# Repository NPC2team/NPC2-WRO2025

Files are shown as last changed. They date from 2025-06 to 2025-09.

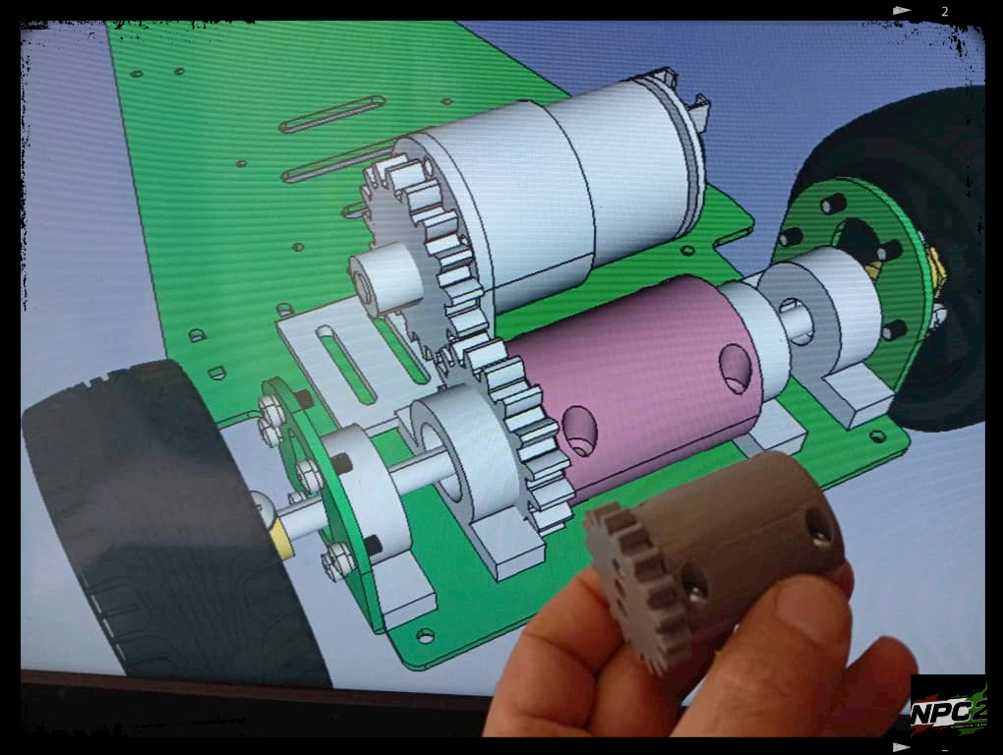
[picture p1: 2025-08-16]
Modifications of the Chassis/017 gear.jpg

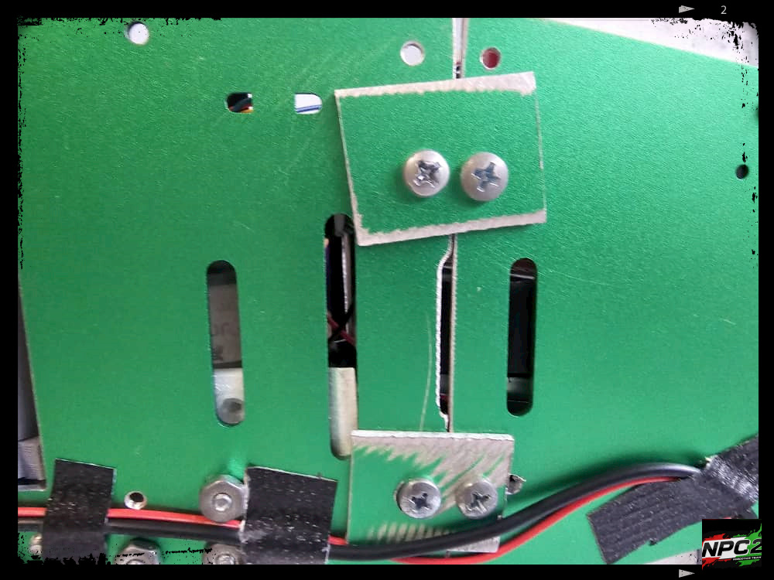
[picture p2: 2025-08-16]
Modifications of the Chassis/011 Joint Chasis2-1.jpg

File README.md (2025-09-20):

NPC2
   

## Table of Contents

- [Our Team](#our-team)
- [Materials](#materials)
- [Car's Construction](#cars-construction)
- [Challenge Problem Solving](#challenge-problem-solving)
- [Electrical Design](#electrical-design)
- [Ackermann Steering Mechanism](#ackeman-steering-mechanism)

## Disclaimer
This repository is the same for the competition of the WRO2025 Venezuela, and the WRO2025 China.
## Our Team

NPC2 is a robotics team from Caracas, Venezuela nationally representing Colegio Jefferson in the World Robotics Olimpiad.  
We have a car named Crazy Diamond and we will be explaning every single detail about him in this repository.
Team Picture:Team FOTO

From left to right: Juan Ignacio González Cardesin, Andrea Jaimes Bselis, Leonardo Carrasquero Recchuiti.
We are competing in the future engineers category of the W.R.O.
The future engineers category consists in 3 mayor challenges:

The first challenge states that the car has to do 3 complete laps in the track and upon finishing stop in the same place it started.

In the second challenge, the car has to do the same three laps while evading obstacles, these oblstacles will vary from color being red or green and depending on the color the car while have to evade them via the right (red) or left (green)  .

During the last challenge the car will start in a parking spot and it has to do the second challenge again, but in this case the car will have to park in the parking spot , this parking must be parelel parking.

## Materials

Watch an explanation of the materials :[Our Materials](https://www.youtube.com/watch?v=jLK10MU_x0E)
[Watch them in accion](https://www.youtube.com/watch?v=ydlA4w6UwqU)
For this competition we had to organize and coordinate with each other in order to narrow down the materials we will use. 
We ended up diciding on the following materials: one motor, one servomotor, one PixyCam2, three ultrasonic sensors, one Arduino R4, one voltage regulator, one H bridge, one 11.1 v battery, and an ackerman steering mecanisim that came with the chasis. 
Below you will see what each material will be used for and why we chose them.

1. The microcontroller that we used is the Arduino R4 WIFI. The Arduino UNO R4 WIFI is an upgraded version of the Arduino UNO, featuring Wi-Fi and Bluetooth connectivity (in this case, due to the competition's rules the Wi-Fi and Bluetooth connectivity is disabled). It’s built around the Renesas RA4M1 microcontroller, which is a 32-bit ARM Cortex-M4 running at 48 MHz, offering significantly more power than the previous 8-bit ATmega328P in the UNO R3. Also this Arduino just needs 5V to start working and in short words, this will be the brain of the car. The Arduino R4 Wi-Fi has 14 digital pins and 6 analogs, so this makes it perfect for us to work. Besides, it's very easy to code in it as it uses a subdivision of C++ called Arduino C++.

Arduino R4:descarga

2. The electronic device we will use to detect colors will be the pixy cam 2 that is a compact, self-contained vision sensor designed to learn objects by their colors. It processes images and quickly outputs data such as the object's signature.
   
Pixy cam: Pixy-2 1-Smart-Vision-Sensor-Object-Tracking-Camera

[Why Pixy?](https://github.com/NPC2team/NPC2-WRO2025/blob/master/Materials/why%20was%20pixy%20chosen.pdf)

3. To help us know where, when, and how to mantain position, we will use ultrasonic sensors that use sonar to measure the distance between themselves and an object. The sensors can measure between 2cm to 400 cm, and they operate at 40 kHz. To complete the challenges, we used 3 ultrasonic sensors. Two of them being in the sides of the car, and one in the front. They are programmed in way so that they will confirm when the car has to cross.

    3D model of ultrasonic sensor: Ultrasonic-Sensor (1)

   The one in the front is a specific model called HRLV, The HRLV‑MaxSonar‑EZ is a high‑resolution, low‑voltage ultrasonic sensor that measures the distance to nearby objects using sound waves.
It offers multiple output formats (analog voltage, pulse width, and serial) for easy integration, and is designed for reliable detection with excellent side‑object rejection.
   It measures distances from 300 mm to 5000 mm (about 12 inches to 16.4 feet) with a 10 Hz read rate, making it perfect for both short‑ and long‑range applications!


5. To power all this we used the Zeee battery Shorty that has 2200 mAh, 3 Lithium polymer. This battery weighs 137 g. It has 11.1V, and its dimmensions are 75mm*34mm*26.5mm.

   Battery: 71m+EHRrMrL

6. To power the motor, and regulate the speed and voltage, we use an H-Bridge, specifically the L298N which is a dual H-bridge motor driver module designed to control the speed and direction of the DC and stepper motors. It operates within a voltage range of 5V to 35V. We connected the H-Bridge to the Arduino using the L298N as an intermediary between the Arduino R4 and the motors.

   L298N: dual-h-bridge-motor-driver-l298n-44325-750x750

7. To regulate the voltage and electricity, we used a voltage regulator that is connected directly to the battery and also powers the DC motor.

   Photo of the voltage regulator:
   modulo-voltaje-ajustable-con-voltimetro-generico-lm2596-step-down-led-digital-2035-2612-1

8. last but not least we have the Servo motor and the DC motor, that are very important because these electronic attachments will help the car move and change dirrections. In the Servo motor's case, it is connected to an Ackerman Steering Wheel that is a physical steering mechanism designed based on Ackermann geometry with the idea that during a turn the inner wheel should turn sharper than the outer wheel so both wheels follow a smooth path. If you are wondering, the Ackerman geometry is a system that ensures a smooth turn by making the inner wheel turn more than the outer one. Meanwhile, the DC motor is part of a mechanism of different gears where it makes the movement of two different wheels possible with just one motor. This mechanism was created using a 3D printer.

   Ackerman steering wheel and Servo photo:
   61U4BQ34BkL _AC_SX522_

   Mechanism of the DC motor:
   

Knowing this, you may wonder what is the chasis that we used, after all it is a very important part of the vehicle because without it, Crazy Diamond wouldn´t exist in the first place.
Well the chasis that we used is a metal chasis that already had the ackerman steering wheel, this chasis can be bought from Amazon. The dimensions of the original chasis are of 337*191*131mm.
[Chasis link](https://www.amazon.com/-/es/inteligente-codificado-estructura-anticolisi%C3%B3n-triangular/dp/B0CWTZC5FQ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) 

Photo of the chasis: 61YIGLu0T0L _AC_SL1500_

## Car's Construccion
Watch an explicatory:[how we created crazy diamond](https://youtu.be/GFbxslP3FUo)

After that we started disarming, destroying, and putting the components that where mencioned before hand.
Adapting the car, evolving it into a wonderful construction, putting the pieces together, and starting to test and view possible ideas for the challenges.

Example of how the proccess should look in Powerpoint: 

The first thing we did to the original chassis was to cut the sides that were near the back wheels and we also cut the chassis in half. We did this so we have less length and avoid the problem of being near the maximum length.

We cut the sides of the chassis so we could add a mechanism that makes it possible for our two back wheels to use only one motor.

Photo of the parts that were about to be cut off:
009 Ajuste Chasis

Photo after the proccess of the car´s adaptation:
018 Enganajes3
019 Enganajes3
017 Enganajes3
011 Joint Chasis2-1

After putting everything where it must go, the car ended up like this:

001 Carro Frontal-1

006 Carro por Debajo

002 Carro Arriba-1

003 Carro Lado Derecho-1

004 Carro Lado Izquierdo-1

005 Carro Trasero-1

## Challenge Problem Solving

[Code explanation](https://www.youtube.com/watch?v=fA16RF1uHUw)

When we finished building the car, we were able to see possible solutions for the challenges.

For the first challenge, we initially planned to do it only with the Pixy camera. The camera signals would be orange and blue, and depending on the color, Crazy Diamond (our car) would spin clockwise or counterclockwise. At the same time, upon detecting the color, a variable will count the number of turns made.
However, we realized it was better to use the ultrasonic sensors for the first challenge, as they allow you to program a code that detects an opening and rotates toward it.
To reinforce the ultrasound idea, we realized it was easier to correct it every time it rotated. This was difficult with the Pixy camera. We also tried to use the VL53L0x or TOF sensor , but we ultimately decided against it because of non consistent measurements when the car was in movement.  We made a document that compared the ultrasonic sensors and the TOF.

[TOFvsULTRASONIC](https://github.com/NPC2team/NPC2-WRO2025/blob/master/Materials/Ultrasonic%20vs%20tof.pdf)

8e7409_c0e539c39a5e4f6d9af293265917e344~mv2

With this we managed to complete the challenge, which can be seen through the link on YouTube.

[First Challenge](https://youtube.com/shorts/cBEeWWgM5bk)

In the second challenge, we combined the Pixy camera with the ultrasonic sensor. The Pixy camera's function would be to detect the red and green blocks. This would allow the car to move toward the blocks and then turn in the direction determined by the block's color.

The ultrasound would have the same function as in Challenge 1: to look for an opening for the car to turn.

Problems in both challenges:

In the first challenge, the main problem was the light illuminating the track, which caused the Pixy camera to misdetect colors or even ignore them, confusing the Arduino.

We managed to solve this problem by using only ultrasound and disabling the Pixy camera for this challenge.

Pixy-2 1-Smart-Vision-Sensor-Object-Tracking-Camera

The second problem was the car's weight, as the battery we were using weighed approximately 500 grams. We solved this by replacing it with a lighter one, that weighs 137 grams.

716CISc+2RL _AC_SX466_

[Why Zeee battery 2200 mAh?](https://github.com/NPC2team/NPC2-WRO2025/blob/master/Energy%20explanation/DETAILED%20POWER%20CONSUMPTION%20ANALYSIS.pdf)

## Electrical Design

[Electric explanation](https://www.youtube.com/watch?v=MQSTbkFTwDA)

The electrical diagrams for the car are shown below.
Final electric diagram with 3 ultrasonic sensors

The circuit starts with a 12V battery that feeds all of the parts. For safety, a main power switch (SW1) turns on or off the whole circuit. The LM2596 step-down regulator is used to convert the 12V supply to a stable 5V output given that some parts need a lower voltage level. These controlled 5 volts are essential so we can power sensitive devices including sensors, the servo motor, and the pixy cam without risking overvoltage damage.

Acting as the main controller of the project is the Arduino UNO R4 WiFi. Directly from the 12V source, the Arduino is driven via its DC connector so ensuring it has enough power even if several accessories are running. Three HC-SR04 ultrasonic sensors are used for distance measurement; one sensor has trigger and echo pins wired to digital pins D2 and D4; another has pins D3 and D5. Moreover, a start button wired to digital pin D10 offers a dependable approach to safely start the action by means of a built-in 10k pull-up resistor.

Concurrent with these sensor links, the circuit drives a motor through an L298N motor driver module. The Arduino controls the enable input and the motor direction inputs (IN3 and IN4) using digital pins D6, D7, and D8. This design is vital for any mobile robotic system because it lets the motor travel in different speeds and directions. This motor controls simplicity and strength making it perfect for applications needing variable movement.

Another important element is the Pixy Cam (CMUcam5), which offers visual processing ability. Through an SPI connection, the Pixy Cam contacts with the Arduino; the MOSI, MISO, and SCK signals are linked to digital pins D11, D12, and D13 respectively, with a dedicated Slave Select (SS) line on pin A0. Real-time picture processing is made possible by this fast communication channel, hence allowing the system to carry out operations such object tracking or visual navigation. Moreover, an SG90 (often) is included to communicate with the mechanical parts, receiving control signals on a PWM pin and working at 5V from the regulator.

The precise pin assignments for sensors, motor drivers, and the camera together with the deliberate distribution of energy from the strong 12V supply to the precisely controlled 5V emphasize the thoughtful integration and equilibrium needed in such an arrangement. Effective mechanical motion control is provided by this design along with sensor data fusing to help with object tracking, obstacle detection, and several user-controllable capabilities.

images

For more details you can check the document: [Diagram Explanation](https://github.com/NPC2team/NPC2-WRO2025/blob/master/Energy%20explanation/DETAILED%20DESCRIPTION%20OF%20ELECTRICAL%20DIAGRAM.pdf)

## ACKEMAN STEERING MECHANISM

An Ackerman steering mechanism is designed to guarantee that a vehicle's front wheels turn at the appropriate angles during a turn, the Ackermann steering mechanism is a cunning mechanical device that enables smooth and effective cornering that helps to avoid tire slippage.
Ackermann steering geometry is a smart configuration of linkages in vehicles designed to guarantee that during a turn the interior and outer front wheels trace separate circular paths. This is because the inner wheel should spin more quickly than the outer wheel to avoid tire scrubbing or slipping, as we said before.


This works because the inner front wheel has to move a closer radius than the outer front wheel as the car turns. In view of the fact, if both wheels were rotated at the same angle, tire wear would occur as the tires scraped against the road, which also reduces control. The Ackermann mechanism solves this issue by arranging the steering angles of each wheel in a way that employs trapezoids to form links. 

We use the Ackerman steering wheel because it reduces tire wear, it improves the handling, and it help the car take directions combined with the servo motor.

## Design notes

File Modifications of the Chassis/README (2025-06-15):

In this file, you will see photos of the changes our team made to the car, The first photo that shows the chassis with some borders colored in black. 
This photo means the parts that we cut off the car that are the sides so we can make a mechanism so the 2 backwheels only use one DC motor.
Then we cut the half of the car that is also colored in black. We cut that so the car length reduces 4 cm aprox.

Then we insert 2 plates underneath the chassis, which are the 2 sides that we cut. We do this so that the 2 halves of the chassis that we cut, come back together.

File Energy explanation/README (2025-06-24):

In this folder you will see every power consumption analysis, each sensors and why we choose them, and the explanation of the final electrical diagram

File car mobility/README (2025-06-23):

In this file you will see different PDF of which materials and components help the  car move and what is the logic behind it

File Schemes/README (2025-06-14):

In this file, you will see two different flow charts corresponding to each of the chalenges and the electrical diagram of the car.

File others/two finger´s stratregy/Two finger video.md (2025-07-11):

[Two finger video](https://youtu.be/SC0VvAZ2L2Q)

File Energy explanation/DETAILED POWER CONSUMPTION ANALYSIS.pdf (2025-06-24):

## DETAILED POWER CONSUMPTION ANALYSIS

### 1. BATTERY SPECIFICATIONS

11.1V 2200mAh LiPo Battery

- Nominal Voltage: 11.1V (3S LiPo)
- Capacity: 2200mAh = 2.2Ah
- Energy Storage: 11.1V × 2.2Ah = 24.42 Wh
- Usable Capacity: ~85% (to prevent deep discharge) = 20.76 Wh
- Voltage Range: 12.6V (full) to 9.6V (empty)

### 2. COMPONENT-BY-COMPONENT POWER ANALYSIS

A. Arduino UNO R4 WiFi (Renesas RA4M1)
Mode | Current Draw Power @ 12V
Idle | 25mA | 0.30W
Processing | 45mA | 0.54W
WiFi Active | 80mA | 0.96W
Typical Running 50mA | 0.60W
B. L298N Motor Driver + DC Motor
Condition | Current Draw Power @ 12V
Driver Quiescent | 35mA | 0.42W
Motor Idle | 50mA | 0.60W
Motor Running (50% PWM) | 400mA | 4.80W
Motor Turning | 600mA | 7.20W
Motor Stalled | 1200mA | 14.40W
Average Navigation | 450mA | 5.40W
C. Servo Motor SG90 (via LM2596)
State | Current @ 5V Power @ 5V Power @ 12V*
Idle | 10mA | 0.05W | 0.06W
Moving | 250mA | 1.25W | 1.47W
Holding Position | 100mA | 0.50W | 0.59W
Average Use | 120mA | 0.60W | 0.71W
D. HC-SR04 Ultrasonic Sensors (×3)
State | Current Each Total (×3) Power @ 5V
Idle | 2mA | 6mA | 0.03W
Measuring 15mA | 45mA | 0.225W
Average | 10mA | 30mA | 0.15W

E. Pixy2 Camera (CMUcam5)
Mode | Current @ 5V Power @ 5V
Idle | 60mA | 0.30W
Tracking 140mA | 0.70W
LED On | 180mA | 0.90W
Typical | 140mA | 0.70W
F. LM2596 Step-Down Regulator
Parameter | Value
Efficiency | 85%
Quiescent Current 5mA
Self Power Loss | 0.06W
Total Overhead | 15% of 5V load
G. System Overhead
Component | Current | Power
Pull-up Resistor | 0.5mA | 0.0025W
Wiring Losses | ~2% | ~0.15W
Total | ~13mA | ~0.15W

### 3. POWER DISTRIBUTION SUMMARY

12V Rail (Direct from Battery)

Component | Current Power
Arduino R4 WiFi | 50mA | 0.60W
L298N + Motor | 450mA | 5.40W
LM2596 Input* | 83mA | 1.00W
Total 12V Rail | 583mA | 7.00W

5V Rail (From Arduino)

Component | Current | Power
3× HC-SR04 | 30mA | 0.15W
Pixy2 Camera | 140mA | 0.70W
Pull-up | 0.5mA | 0.0025W
Total 5V Arduino | 170.5mA | 0.85W

5V Rail (From LM2596)

Component Current Power
Servo SG90 | 120mA | 0.60W

### 4. OPERATING SCENARIOS

Scenario 1: Straight Line Navigation

Arduino: | 50mA × 12V = 0.60W

### Motor (40% PWM): 350mA × 12V = 4.20W

Servo (center): | 50mA × 5V = 0.25W (0.29W @ 12V)
Sensors: | 30mA × 5V = 0.15W
Pixy2: | 140mA × 5V = 0.70W
Overhead: | 0.15W
TOTAL: | ~480mA @ 12V = 6.19W

Scenario 2: Turning Maneuvers

Arduino: | 50mA × 12V = 0.60W

### Motor (60% PWM): 550mA × 12V = 6.60W Servo (turning): 250mA × 5V = 1.25W (1.47W @ 12V)

Sensors: | 45mA × 5V = 0.225W
Pixy2: | 140mA × 5V = 0.70W
Overhead: | 0.20W
TOTAL: | ~750mA @ 12V = 9.58W

Scenario 3: Obstacle Detection & Processing

Arduino (peak): | 70mA × 12V = 0.84W
Motor (stop): | 50mA × 12V = 0.60W

### Servo (active): 150mA × 5V = 0.75W (0.88W @ 12V) Sensors (all): 45mA × 5V = 0.225W Pixy2 (LED on): 180mA × 5V = 0.90W

Overhead: | 0.15W
TOTAL: | ~380mA @ 12V = 4.56W

### 5. BATTERY LIFE CALCULATIONS

Average Power Consumption Profile

Assuming typical maze navigation:

- 60% straight navigation: 6.19W
- 30% turning: 9.58W
- 10% obstacle processing: 4.56W

Weighted Average: (0.6 × 6.19) + (0.3 × 9.58) + (0.1 × 4.56) = 7.05W

Battery Runtime Calculations

Usable Energy: 20.76 Wh (85% of 24.42 Wh)

Average Power: 7.05W

Runtime = 20.76 Wh ÷ 7.05W = 2.94 hours

### 6. PEAK CURRENT ANALYSIS

Maximum Simultaneous Draw:

Arduino (WiFi TX): | 100mA
Motor (stall): | 1200mA
Servo (stall): | 300mA (60mA @ 12V via LM2596)

Sensors (all active): 45mA @ 5V

Pixy2 (LED on): 180mA @ 5V

PEAK CURRENT: ~1400mA @ 12V (15.5W)

Battery C-Rating Check:

- Required: 1400mA ÷ 2200mAh = 0.64C
- Typical LiPo: 20C capable
- Battery can easily handle peak loads

CONCLUSION

11.1V 2200mAh Battery Performance:

- Adequate Capacity: 2.94 hours typical runtime
- Sufficient Current: Can deliver 1.4A peaks easily
- Good Voltage Stability: Maintains >10V for 90% of discharge
- Safety Margin: 20C rating >> 0.64C required

The 11.1V 2200mAh battery is well-suited for this application, providing nearly 3 hours of runtime with comfortable current delivery margins. For competition use, this allows multiple runs with battery to spare.

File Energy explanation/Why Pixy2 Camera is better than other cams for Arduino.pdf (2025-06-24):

## Why Pixy2 Camera is Superior for Arduino-Based Color Obstacle Avoidance

CAMERA OPTIONS COMPARISON

Available Cameras for Arduino:

1. Pixy2 (CMUcam5) - Dedicated color tracking processor
2. OpenMV - Python-programmable vision module
3. ESP32-CAM - WiFi camera with processor
4. OV7670 - Basic camera module
5. ArduCAM - Various models with FIFO buffer
6. HuskyLens - AI vision sensor

### 1. COLOR DETECTION CAPABILITIES

Pixy2 Advantages:

- Hardware-accelerated color detection at 60 FPS
- Can track 7 color signatures simultaneously
- Built-in color-connected components (CCC) algorithm
- No Arduino processing required - outputs object coordinates directly
- Automatic white balance and exposure adjustment

Other Cameras:

OpenMV: 15-30 FPS color detection (Python overhead)

ESP32-CAM: Requires separate processor, 10-15 FPS to Arduino

OV7670: Raw pixels only - Arduino too slow for processing

ArduCAM: 1-5 FPS with Arduino processing

HuskyLens: 20 FPS but limited to preset colors

### 2. REAL-TIME PERFORMANCE COMPARISON

Camera | Color Detection FPS | Latency | Arduino Load
Pixy2 | 60 FPS | <20ms | ~5% (SPI only)
OpenMV | 15-30 FPS | 50-100ms | ~10% (UART)
ESP32-CAM | 10-15 FPS | 100-200ms | ~20% (Serial)
OV7670 | <1 FPS | >1000ms | 100% (unusable)
ArduCAM | 1-5 FPS | 200-500ms | ~80%
HuskyLens | 20 FPS | 50ms | ~10% (I2C)

### 3. COLOR OBSTACLE AVOIDANCE SPECIFIC FEATURES

Pixy2 Unique Advantages:

1. Color Code Detection: Can identify combinations of colors (e.g., red-green-red pattern)
2. Object Size Filtering: Reports width/height for distance estimation
3. Tracking Algorithm: Maintains object ID between frames
4. Pan/Tilt Support: Can actively track moving obstacles

### 4. TECHNICAL SPECIFICATIONS COMPARISON

Feature | Pixy2 | OpenMV | ESP32-
CAM
| | OV7670 | ArduCA M | HuskyLens
Resolution | 316x208 | 320x240 | 1600x120
| 0 | 640x480 | Various | 320x240
Processor | NXP
LPC4330
STM32H743 | ESP32 | None | None | Kendryte K210
Color | Built-in | Programmabl | Requires | Manual | Manual | Pre-trained
Tracking | | e | coding
Interface | SPI/I2C/U
ART

SPI/I2C/UAR
T

WiFi/Seri
al
Parallel | SPI | I2C/UART

### 5. COLOR DETECTION ALGORITHMS

Pixy2 Color Connected Components (CCC):

- HSV color space processing in hardware
- Automatic region growing algorithm
- Real-time connected component labeling
- Outputs: X, Y, Width, Height, Signature ID

Why Others Struggle:

OV7670/ArduCAM:

- Must transfer raw RGB pixels (307KB/frame)
- Arduino processes each pixel (too slow)
- No hardware acceleration

ESP32-CAM:

- Powerful but separate processor
- Complex integration with Arduino
- WiFi overhead if used

OpenMV:

- Excellent but overkill for simple color tracking
- More expensive than Pixy2
- Python interpreter overhead

### 6. OBSTACLE AVOIDANCE PERFORMANCE

Critical Metrics for Navigation:

Response Time to New Obstacle:

- Pixy2: 16ms (1 frame at 60 FPS)
- OpenMV: 33-66ms
- ESP32-CAM: 100-200ms
- OV7670: >1000ms (unusable)

Multiple Obstacle Tracking:

- Pixy2: 7 colors/objects simultaneously
- HuskyLens: 1-2 objects
- Others: Depends on Arduino processing power

### 7. POWER AND RESOURCE EFFICIENCY

Camera | Current Draw Arduino RAM Used Arduino Flash Used
Pixy2 | 140mA | <1KB | ~10KB library
OpenMV | 140mA | 2KB | 15KB library
ESP32-CAM | 160mA | 2KB | 20KB library
OV7670 | 40mA | 8KB+ buffer | 30KB+ code
ArduCAM | 80-120mA | 4KB buffer | 25KB code

CONCLUSION: Why Pixy2 was our choice

For Arduino-based color obstacle avoidance, Pixy2 is the optimal choice because:

1. Dedicated Vision Processor: Offloads ALL vision processing from Arduino
2. Real-time Performance: 60 FPS ensures immediate obstacle detection
3. Proven Reliability: Used in thousands of robotics projects
4. Simple Integration: 5 lines of code vs. hundreds
5. Multiple Object Tracking: Essential for complex environments
6. Power Efficiency: Comparable to alternatives despite superior performance

Bottom Line: While ESP32-CAM is cheaper and OpenMV is more flexible, Pixy2's purpose-built design for color tracking makes it the superior choice for real-time obstacle avoidance. The hardware acceleration and zero Arduino processing overhead are game-changers for responsive navigation.

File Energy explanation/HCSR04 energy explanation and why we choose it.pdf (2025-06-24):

Why we choose HC-SR04 Ultrasonic Sensors and not VL53L0X TOF Sensors?

### 1. TECHNOLOGY DIFFERENCES

HC-SR04 (Ultrasonic)
- Uses sound waves at 40kHz frequency
- Measures time-of-flight of acoustic pulses
- Wavelength: ~8.5mm (much larger than surface irregularities)
- Detection cone: 15-30° typical
VL53L0X (TOF)
- Uses infrared laser at 940nm wavelength
- Measures time-of-flight of light pulses
- Wavelength: ~0.94μm (microscopic)
- Detection cone: 25° typical (but effective spot is smaller)

### 2. PERFORMANCE WITH BLACK SURFACES

HC-SR04 Advantages:
- Acoustic waves are color-blind - sound reflects equally from black, white, or any colored surface
- Surface absorption affects amplitude, not time measurement
- Black surfaces reflect ultrasound just as effectively as white surfaces
- No dependency on optical properties of the target
VL53L0X Disadvantages:
- Black surfaces absorb ~90-95% of IR light
- Dramatically reduced signal-to-noise ratio
- May fail to detect black walls entirely at longer distances
- Requires significantly more power to compensate for absorption
- False readings or "no detection" errors are common

### 3. ANGLED SURFACE BEHAVIOR

HC-SR04 with Angled Surfaces:
- Wide beam pattern (15-30°) captures reflections even from angled surfaces
- Sound waves create multiple reflection paths
- Can detect walls at angles up to 45° reliably
- Diffuse reflection pattern helps maintain detection
VL53L0X with Angled Surfaces:
- Specular reflection - laser beam reflects away from sensor
- Narrow effective beam requires perpendicular surfaces
- Angles >15° often result in no return signal
- Mirror-like reflection on smooth surfaces causes complete signal loss

### 4. NAVIGATION SPECIFIC ADVANTAGES

Wall Following Capability:
HC-SR04: Reliable detection at various angles

- Can detect walls while turning
- Maintains readings during diagonal approaches
- Effective for corner detection

VL53L0X: Loses signal during turns
- Requires perpendicular alignment
- Misses angled walls
- Poor corner detection

Opening Detection:
The HC-SR04's wider beam pattern actually helps in detecting openings:
- Gradual distance increase as approaching an opening
- Natural averaging effect reduces noise
- Clear threshold detection for 70cm+ openings

### 5. TECHNICAL COMPARISON FOR BLACK MAZE WALLS

Parameter | HC-SR04 | VL53L0X
Black Surface Range | 2-400cm | 5-50cm (unreliable)
Angled Surface (30°) | 90% detection | <20% detection
Response Time | 20-30ms | 20-30ms
Power Consumption | 15mA | 20mA average
Reliability in Maze | Excellent | Poor

CONCLUSION
The VL53L0X's advantages (precision, size, speed) are negated by its fundamental inability to reliably detect black surfaces at angles - a critical requirement for maze navigation. The HC-SR04's "inferior" technology actually becomes superior for this specific application where robust detection matters more than precision.

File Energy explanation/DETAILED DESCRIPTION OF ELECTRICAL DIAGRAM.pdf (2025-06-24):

## DETAILED DESCRIPTION OF ELECTRICAL DIAGRAM

### 1. POWER SYSTEM

Main Power Source

- Battery: 12V DC
- Main Switch (SW1): Controls entire system power via ON/OFF switch that interrupts battery positive terminal

Voltage Regulation

- LM2596 Step-Down Module:
- Input: 12V from main bus (after switch)
- Output: Adjustable 5V via potentiometer
- Type: Buck switching converter (high efficiency ~92%)
- Includes operation indicator LED
- Powers servo motor exclusively

Power Distribution

- 12V Bus: Directly powers:
- L298N Motor Driver (VS terminal)
- Arduino R4 WiFi (via DC Jack)
- LM2596 regulator input
- Arduino 5V Bus: Powers:
- 3 HC-SR04 sensors
- Pixy Camera
- Start button pull-up

### 2. MAIN CONTROLLER

Arduino UNO R4 WiFi

- Processor: Renesas RA4M1 (ARM Cortex-M4 @ 48MHz)
- Integrated WiFi connectivity
- Power: 12V via DC Jack (internal regulation to 5V)
- Provides regulated 5V for peripherals

### 3. MOTION SYSTEM

DC Motor

- Controlled by L298N driver

- L298N Connections:
- ENB → Pin D6 (PWM speed control)
- IN3 → Pin D8 (direction)
- IN4 → Pin D7 (direction)
- OUT3/OUT4 → DC motor terminals
- VS → 12V from main bus
- GND → Common ground

Servo Motor SG90

- Vehicle steering control
- Connections:
- PWM → Pin D9 (control signal)
- VCC → 5V from LM2596 regulator (dedicated power)
- GND → Common ground

### 4. SENSOR SYSTEM

Three HC-SR04 Ultrasonic Sensors

### 1. RIGHT Sensor:

- TRIG → Pin D2
- ECHO → Pin D3
- VCC → Arduino 5V
- GND → Common ground

### 2. LEFT Sensor:

- TRIG → Pin D4
- ECHO → Pin D5
- VCC → Arduino 5V
- GND → Common ground

### 3. FRONT Sensor:

- TRIG → Pin A1
- ECHO → Pin A2
- VCC → Arduino 5V
- GND → Common ground

Pixy Camera (CMUcam5)

- SPI interface for computer vision
- SPI Connections:
- MISO → Pin D12

- MOSI → Pin D11
- SCK → Pin D13
- SS → Pin A0
- VCC → Arduino 5V
- GND → Common ground

### 5. CONTROL SYSTEM

START Button

- Connected to Pin D10
- 10kΩ pull-up resistor to 5V
- Pressing connects pin to ground (inverse logic)
- Allows robot program initialization

### 6. DETAILED CONNECTIONS

Digital Pins Used:

- D2: Right sensor TRIG
- D3: Right sensor ECHO
- D4: Left sensor TRIG
- D5: Left sensor ECHO
- D6: Motor ENB (PWM)
- D7: Motor IN4
- D8: Motor IN3
- D9: Servo PWM
- D10: Start button
- D11: MOSI (SPI - Pixy)
- D12: MISO (SPI - Pixy)
- D13: SCK (SPI - Pixy)

Analog Pins Used:

- A0: SS (Pixy Camera)
- A1: Front sensor TRIG
- A2: Front sensor ECHO

### 7. POWER FLOW

1. 12V Battery → ON/OFF Switch → 12V Bus
2. 12V Bus splits to:
- → Arduino DC Jack (internal regulation)
- → L298N VS (motor power)
- → LM2596 IN (to generate 5V)
3. Arduino 5V pin → HC-SR04 Sensors + Pixy + Pull-up

4. LM2596 OUT → Servo motor (dedicated 5V)

### 8. IMPORTANT FEATURES

Common Ground (GND)

- All components share same ground reference
- Ground bus connects: battery, Arduino, L298N, LM2596, sensors, servo, and Pixy

Protections

- Main switch for complete power cutoff
- Separate regulation for servo (prevents voltage drops)
- Pull-up on Start button (prevents erratic readings)

Diagram Color Codes

- Thick black: Main power lines
- Thin black: Digital signals
- Blue: Motor control signals
- Green: Ultrasonic sensor signals
- Orange: Servo PWM signal
- Purple: Pixy SPI bus
- Red: 5V from regulator to servo

### 9. DESIGN ADVANTAGES

1. Robust power supply: Separate regulation prevents interference
2. Modular: Easy to add/remove components
3. Diagnostics: LED on LM2596 indicates operation
4. Flexibility: Integrated WiFi allows remote control
5. Safety: Main switch cuts all power
6. Complete navigation: 3 sensors cover 180° vision

This design enables an autonomous navigation robot capable of detecting obstacles in three directions, with computer vision and precise motion control, all with a robust and well-organized electrical architecture.

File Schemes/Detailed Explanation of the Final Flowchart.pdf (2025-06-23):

Detailed Description of the Autonomous Navigation System
1. Initialization and Boot
The system begins with an initialization phase where all hardware components are configured. The home button pin is first set with internal pull-up resistance, allowing it to detect when the user is ready to start. The program waits indefinitely until the button is pressed, displaying the message "Press the button to start" through the serial port.
Once the button press is detected, the system waits for it to release and then enters a 2-second pause before proceeding. During this time set up:
Motor pins (ENB, IN3, IN4) for speed and steering control.
The servo motor on pin 9, positioning it at its central angle (88°).
The three ultrasonic sensors with their respective trigger and echo pins.
2. Main Operating Cycle
The program enters a continuous loop that executes the following operations every 50 milliseconds:
2.1 Status Check
First, check if the variable CareerFinished is true. If it is, it stops the engine and stays in that state indefinitely.
2.2 Sensor Reading
If the race is not over, proceed to ALWAYS read the three ultrasonic sensors:
Right sensor: Measures the distance to the right wall.
Left sensor: Measures the distance to the left wall.
Front sensor: Measures forward distance.
Each sensor takes 3 consecutive readings and calculates the average for a more reliable measurement. Invalid readings (greater than 400cm or without echo) are discarded. The entire reading process takes approximately 180ms.
3. Navigation Logic
The control logic is divided into two distinct behaviors depending on whether the vehicle has made its first turn or not:
3.1 Before the First Spin (Spin Counter = 0)
In this initial phase, the vehicle has a "confident" and simplified behavior:

Opening detection: Checks if there is an opening (distance > 100cm) to the right or left.

If it detects opening on the right:
Rotates the servo to 133° and keeps the motor moving forward for 1800ms
Set turn direction = 0 to remember to keep turning right
Reduces motor speed from 122 to 120 (post-turn fine adjustment)
If it detects opening on the left:
Rotate the servo to 33° and keep the motor moving forward for 1800ms
Set turn direction = 1 to remember to keep turning left

If it detects no openings: Just go straight WITHOUT applying any correction, keeping the servo at 88°
After any turn, apply an additional delay of 2000ms to avoid multiple detections of the same aperture.
3.2 After the First Spin (Spins counter > 0)
Once the first turn has been made, the behavior changes according to the direction set:
If turn direction = 0 (right):
Just look for openings on the right
If there is no opening, apply the proportional correction system

If turn direction = 1 (left):
Just look for openings on the left-If there is no opening, apply the proportional correction system-
4. Proportional Correction System
This system is only activated after the first turn and when both walls are present (distance < 100cm on both sides):
Behaviour:
If you need minor adjustments:

Calculation: difference = distanceLeft – distanceRight. If it differs > 15cm: It is closer to the right wall.
Applies soft correction to the left (68° servo).
Holds for 325ms.

If it differs < -15cm: It is closer to the left wall Applies gentle correction to the right (servo at 105°). Holds for 325ms.

If -15cm ≤ difference ≤ 15cm: It is sufficiently centered Continue straight without correction.

5. Turn Control and Completion
5.1 Spin Counter
Each time the vehicle detects and takes an opening: Increments CounterSpin
Shows by serial the turn number and direction After each turn, wait 2000ms before continuing

5.2 Completion of the Race
When the Spins counter reaches 12 (equivalent to 3 full spins): Displays "Last Spin Completed!"
Center the servo and move straight forward for an additional 2000ms Completely stops the engine
Set CareerFinished = true
The program remains in a stopped state
6. Security Features
Average Readings: Reduces measurement errors

Continuous check during corrections: You can cancel a correction if you detect an opening Post-turn delays: Avoid detecting the same opening multiple times.
Front Sensor: Adds an extra layer of safety against frontal collisions.
Timeouts on sensors: Prevents the program from freezing if a sensor fails.
7. Debug Information
The system sends continuously by serial port (115200 baud):
The three distances measured in each cycle
Opening detection
Type of correction applied (AGGRESSIVE/SOFT)
Number of turns made
Special states (start, end)

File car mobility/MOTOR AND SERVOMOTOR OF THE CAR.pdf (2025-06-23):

## MOTOR AND SERVOMOTOR OF THE

## CAR

In this PDF, you will see what motor we use, what servomotor we use, how we select them, and how we put it in the car.

## MOTOR

For the car we use a DC motor with an encoder, a DC motor with encoder combines a simple brushed motor where DC voltage spins the armature with an optical or magnetic sensor that generates pulse (quadrature) signals! A controller uses these signals to track speed and position for precise, closed loop control!

The model of the DC motor with an encoder that we use is MD520Z19_12V. That is this one:

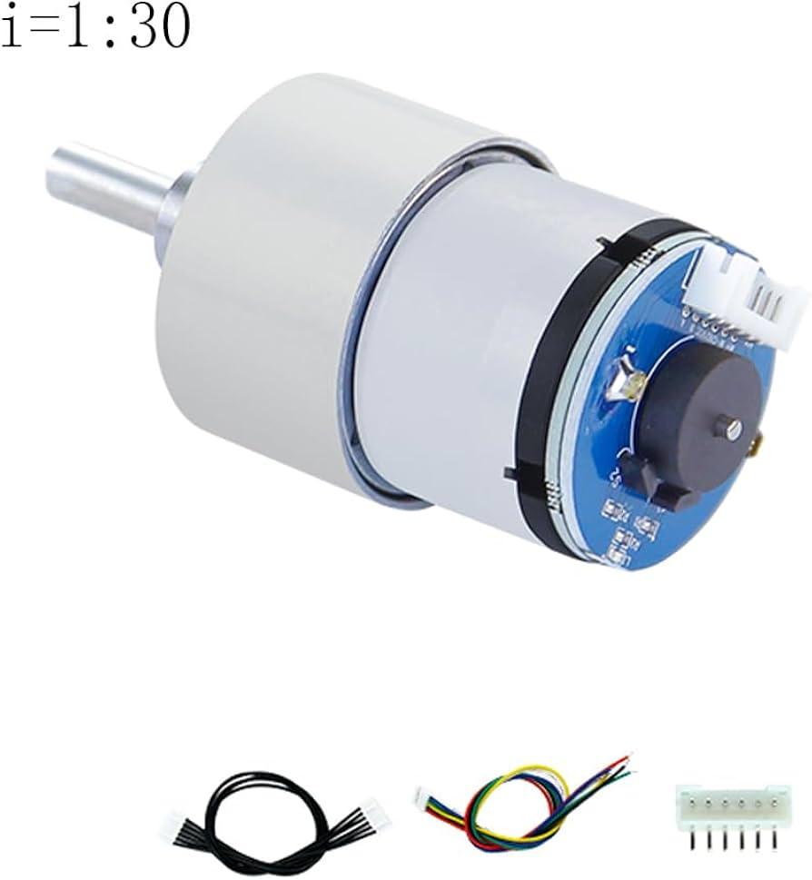
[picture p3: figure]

The main reasons we use this motor are:

- The rated voltage is of 12V which is perfect for our battery and car.
- The motor can reach 11000 rpm before deacceleration.
- It has an encoder which can help us.
- And the last reason is that compare to other DC motors, this one has more power.

## SERVOMOTOR

A servomotor is a type of electric motor designed for precise control of angular or linear position, speed, and torque.

We use a 20 Kg Cm servomotor, and the model is YB-P20M where the voltage is of 7.6V. The main reason we use this servomotor is because it helps us to change the direction of the car and it complements the Ackerman steering mechanism.

The servo motor is the one below:

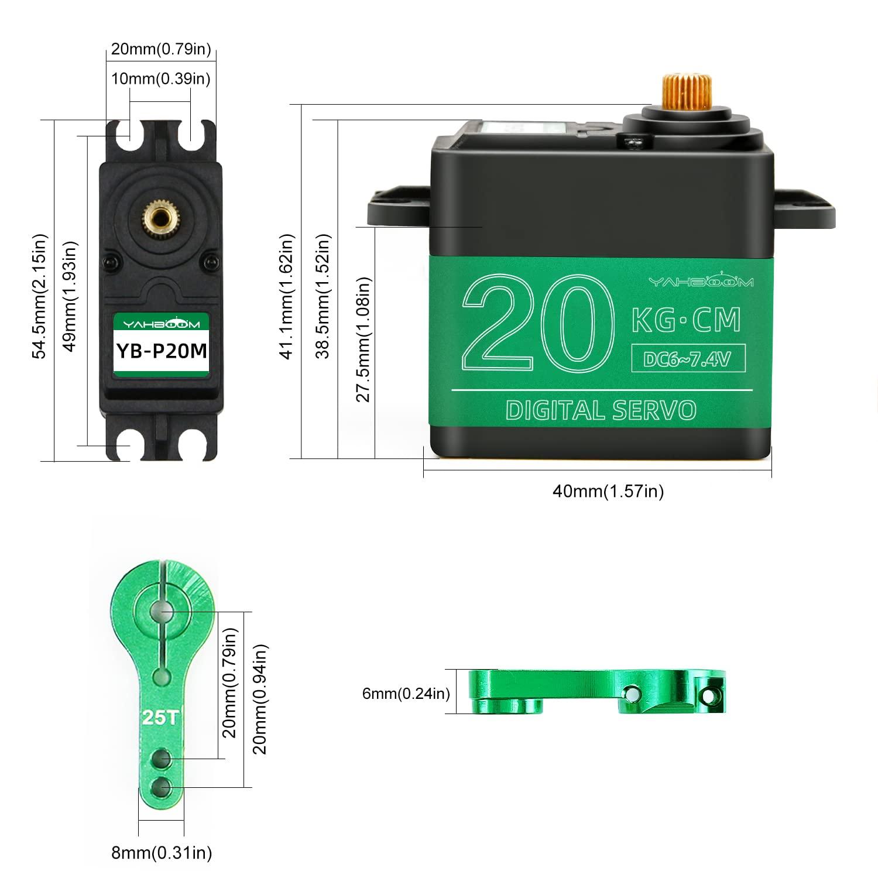
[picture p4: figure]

## HOW WE PUT IT ON THE CAR

First of all, the servo motor is installed in the front of the chassis, and it is fixed by some screws.

The motor is in the back of the chassis and we put a mechanism that is this one

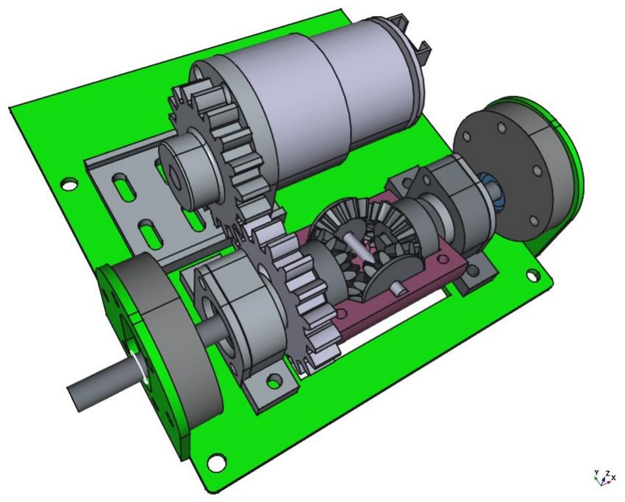
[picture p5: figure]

All this mechanism are created using 3D printer.

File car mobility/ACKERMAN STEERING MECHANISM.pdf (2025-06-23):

## ACKERMAN STEERING MECHANISM

Designed to guarantee that a vehicle's front wheels turn at the appropriate angles during a turn, the Ackermann steering mechanism is a cunning mechanical device that enables smooth and effective cornering that helps to avoid tire slippage.

## ACKERMAN STEERING GEOMETRY

Ackermann steering geometry is a smart configuration of linkages in vehicles designed to guarantee that during a turn the interior and outer front wheels trace separate circular paths. This is because the inner wheel should spin more quickly than the outer wheel to avoid tire scrubbing or slipping, as we said before.

This works because the inner front wheel has to move a closer radius than the outer front wheel as a car turns. In view of the fact if both wheels were rotated at the same angle, wear would occur as the tires scraped against the road, which also reduces control. The Ackermann mechanism solve this issue by arranging the steering angles of each wheel in a way that employs trapezoids to form links.

An example of this is the picture below:

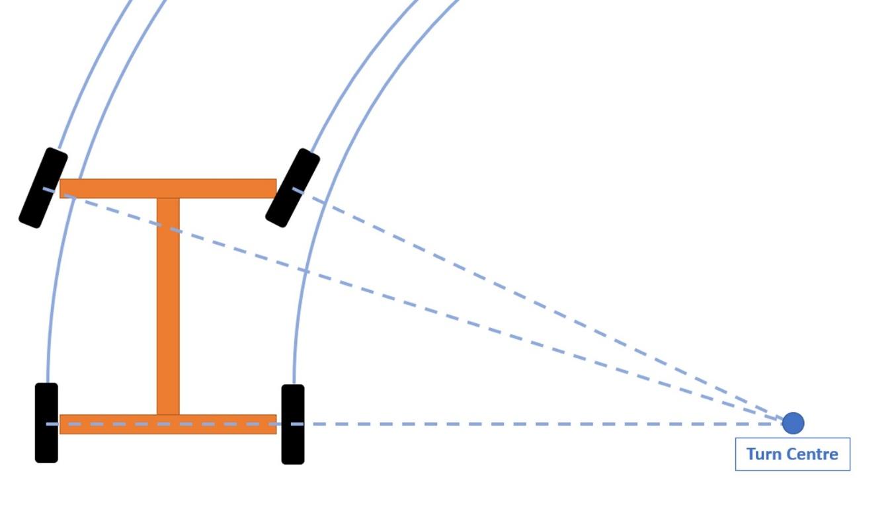
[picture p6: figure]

## KEY COMPONENTS

Steering arms attached to each front wheel.

- A tie rod connecting the arms.
- A steering linkage that moves the tie rod when the steering wheel is turned.

## WHY WE USE IT?

We use the Ackerman steering wheel because it reduces tire wear, it improves the handling, and it help the car take directions combined with the servo motor.

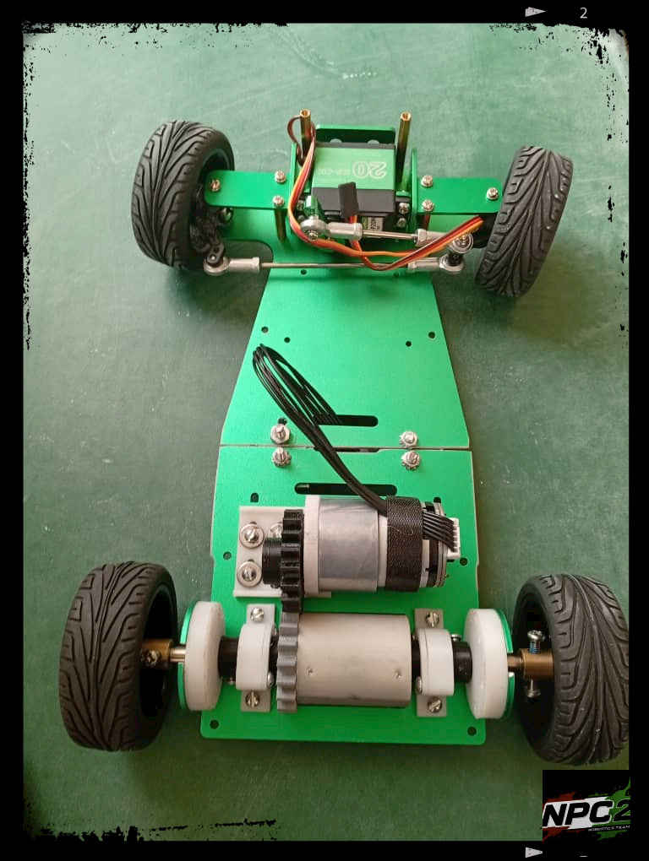
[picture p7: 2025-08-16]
Modifications of the Chassis/019 gear3.jpg

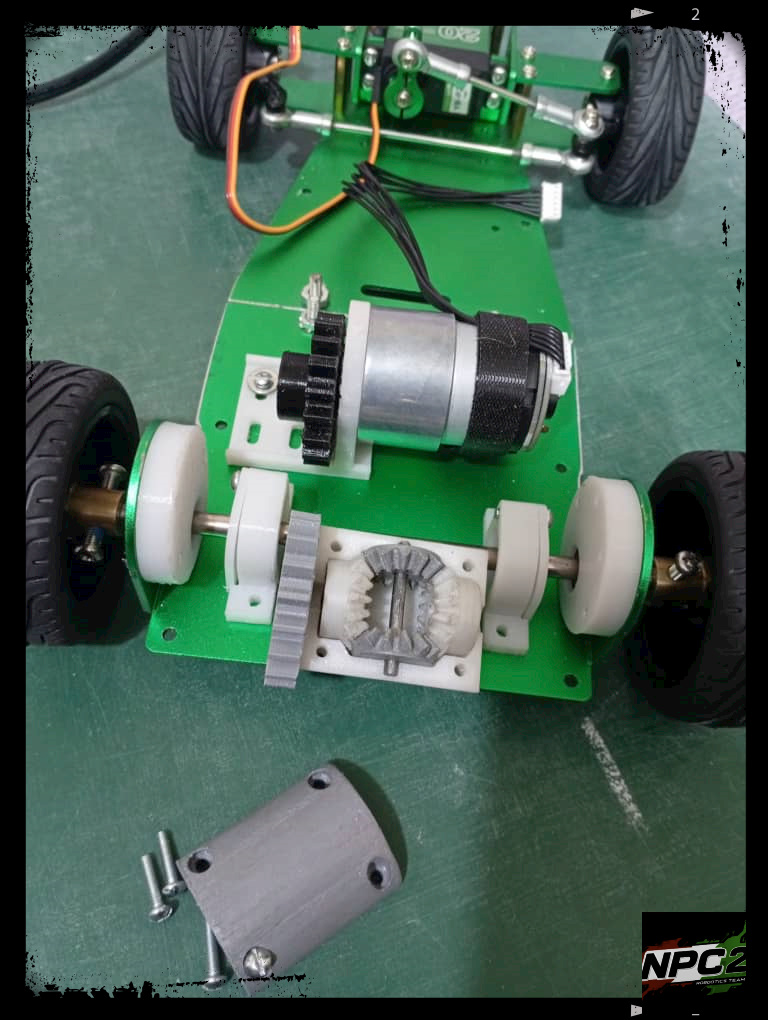
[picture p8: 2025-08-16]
Modifications of the Chassis/018 gears2.jpg

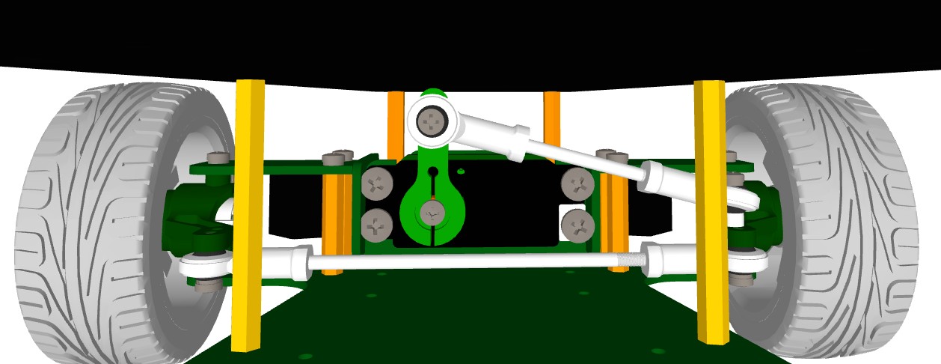
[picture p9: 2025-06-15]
Models/Ackerman y Servo.jpg

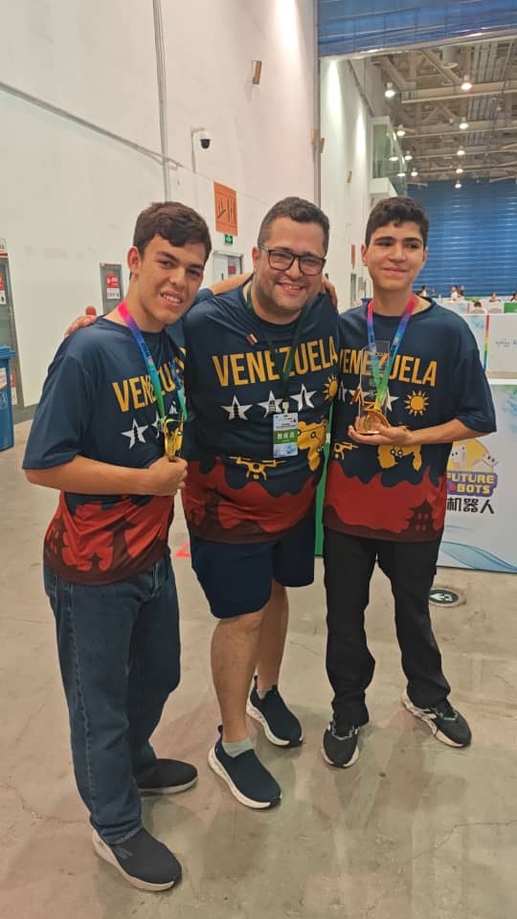
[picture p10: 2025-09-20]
others/photos of the competition from China/Photo with our coach.JPG

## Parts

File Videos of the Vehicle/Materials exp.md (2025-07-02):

[Our Materials](https://www.youtube.com/watch?v=jLK10MU_x0E)

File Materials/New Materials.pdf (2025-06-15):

# NEW MATERIALS

In these presentation, you will see the materials that we are going to use for the car.

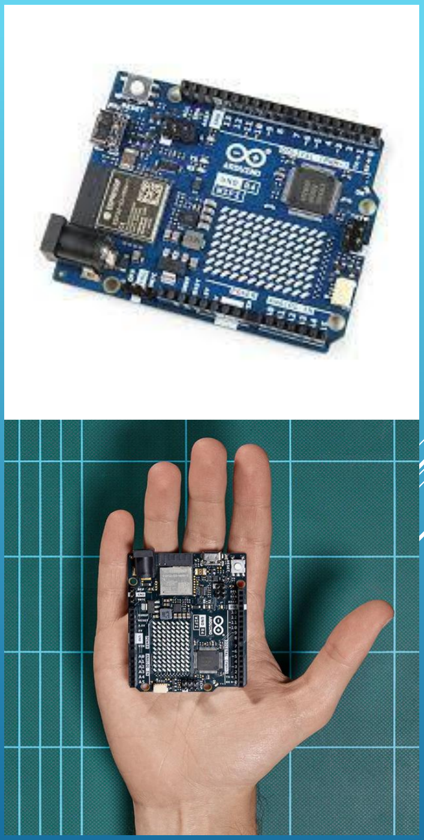
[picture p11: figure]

# MICROCONTROLLER:

The microcontroller that we used is the Arduino R4 WIFI. The Arduino UNO R4 WIFI is an upgraded version of the Arduino UNO, featuring Wi-Fi and Bluetooth connectivity (in this case, due to the competition the Wi-Fi and Bluetooth connectivity is disable). It’s built around the Renesas RA4M1 microcontroller, which is a 32-bit ARM Cortex-M4 running at 48 MHz, offering significantly more power than the previous 8-bit ATmega328P in the UNO R3.

Important features:
- - Hardware Compatibility: Maintains the same form factor, pinout, and 5V operating voltage as the UNO R3.
- - Comes with expanded memory and a faster clock speed than Arduino R3
- - Supports up to 24V input, making possible the connection of different motors, LED strips, and many more.
- - Offers additional pins for power control.

# PIXY CAM:

For this car, we used the original Pixy Cam. The Pixy Cam is a compact, self-contained vision sensor designed to learn objects by their colors. It processes images and quickly outputs data such as the object's signature, x/y coordinates, width, and height so you get only the information you need in real time.

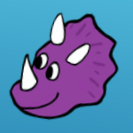
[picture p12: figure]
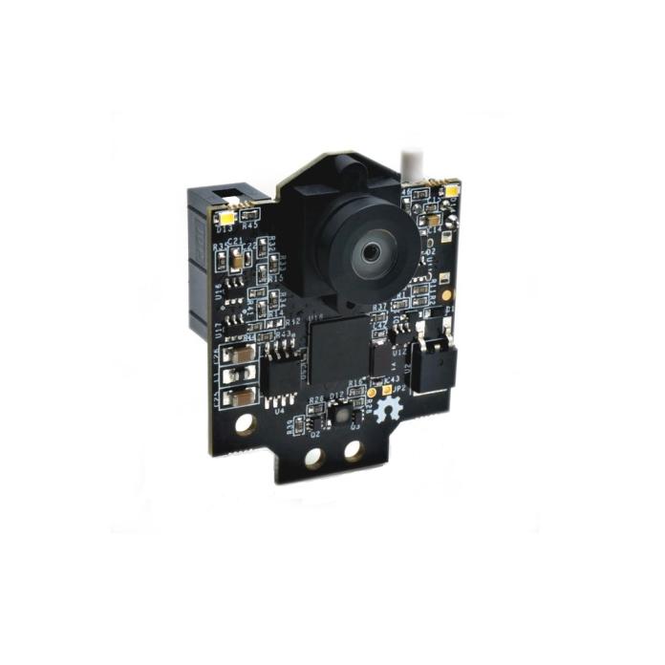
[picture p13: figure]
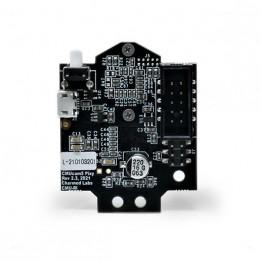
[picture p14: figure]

# ULTRASONIC SENSORS:

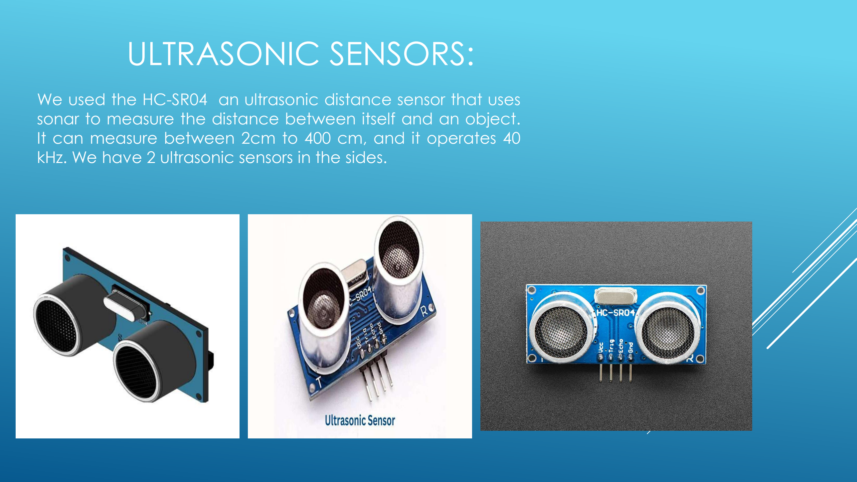
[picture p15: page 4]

We used the HC-SR04 an ultrasonic distance sensor that uses sonar to measure the distance between itself and an object. It can measure between 2cm to 400 cm, and it operates 40 kHz. We have 2 ultrasonic sensors in the sides.

# BATTERY

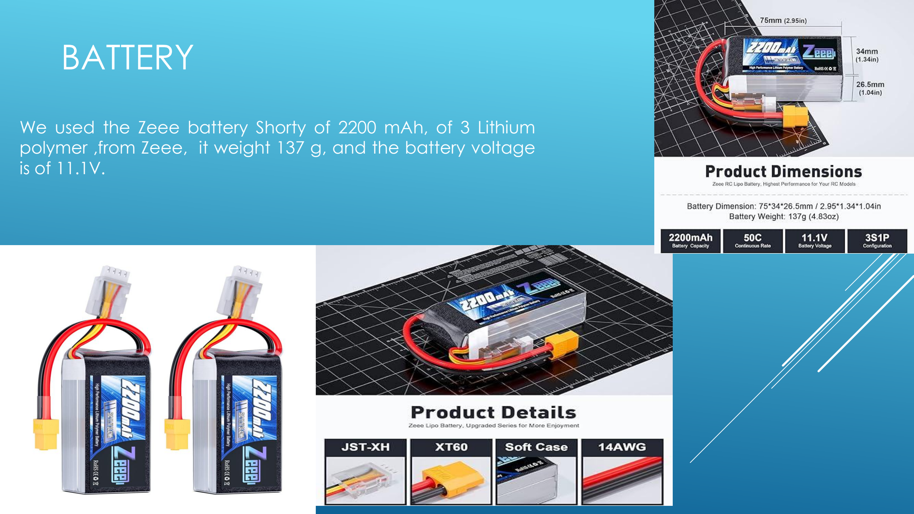
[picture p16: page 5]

We used the Zeee battery Shorty of 2200 mAh, of 3 Lithium polymer ,from Zeee, it weight 137 g, and the battery voltage is of 11.1V.

# H-BRIDGE

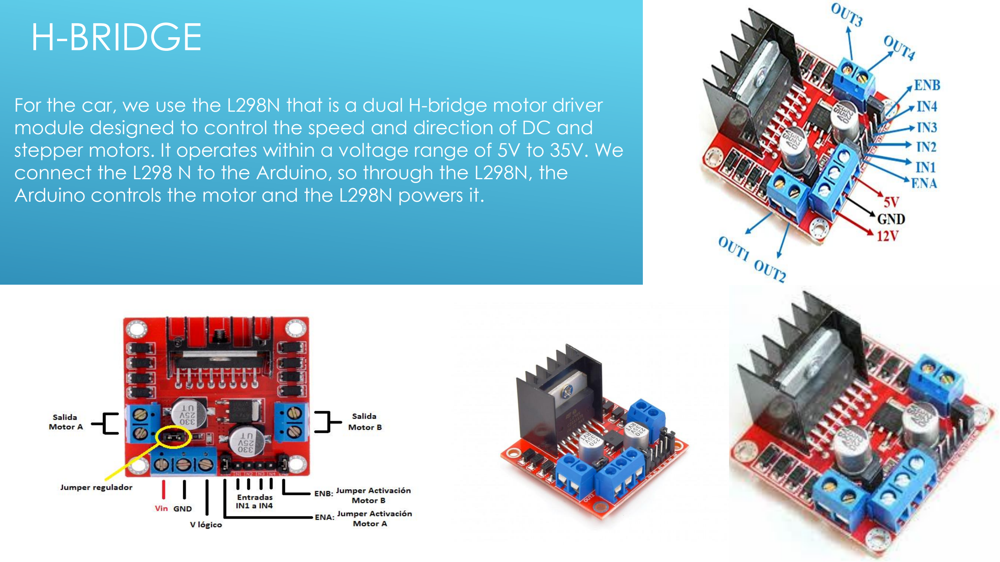
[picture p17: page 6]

For the car, we use the L298N that is a dual H-bridge motor driver module designed to control the speed and direction of DC and stepper motors. It operates within a voltage range of 5V to 35V. We connect the L298 N to the Arduino, so through the L298N, the Arduino controls the motor and the L298N powers it.

# VOLTAGE REGULATOR

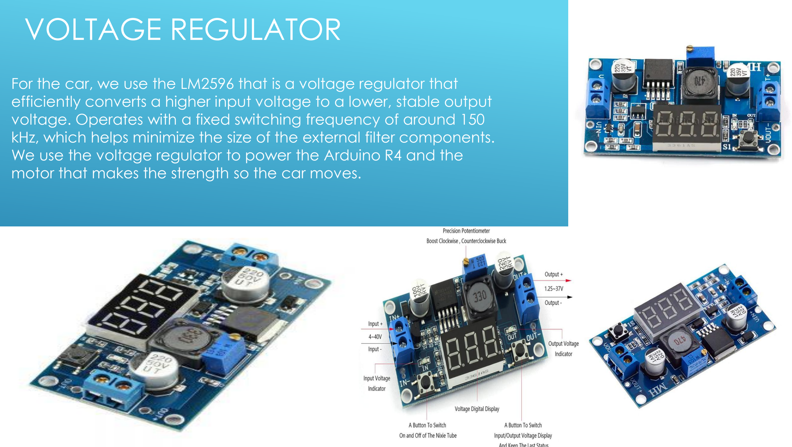
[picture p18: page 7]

For the car, we use the LM2596 that is a voltage regulator that efficiently converts a higher input voltage to a lower, stable output voltage. Operates with a fixed switching frequency of around 150 kHz, which helps minimize the size of the external filter components. We use the voltage regulator to power the Arduino R4 and the motor that makes the strength so the car moves.

# ACKERMAN STEERING SYSTEM

An Ackermann steering system is a physical steering mechanism designed based on Ackermann geometry with the idea that during a turn the inner wheel should turn sharper than the outer wheel so both wheels follow smooth path. In our case we only used one DC motor and for that we made a lot of changes like a cut in the sides of the chassis.

With a servo motor, the
Ackerman Steering system help the car moves and change
direction.


# MOTORS

The car has a DC gear Motor and a servo motor. DC gear motor is a motor with an integrated gearbox. This gearbox help to control and regulate the speed the motor does. In the real car, we just use one DC motor.

The servo motor is a motor that changes the direction of the car.


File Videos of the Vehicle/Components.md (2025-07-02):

[Components](https://www.youtube.com/watch?v=ydlA4w6UwqU)

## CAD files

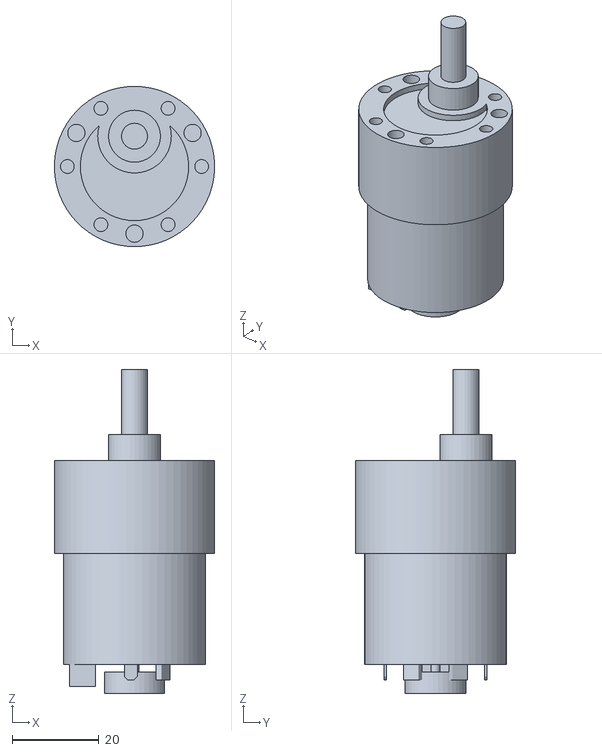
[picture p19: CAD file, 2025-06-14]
Models/Motor.stl
37.0 x 37.0 x 74.8

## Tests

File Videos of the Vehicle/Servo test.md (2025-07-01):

[Servo motor video](https://www.youtube.com/shorts/oXhzuwi9pfY)

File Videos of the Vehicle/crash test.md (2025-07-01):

[Crash protocol](https://youtube.com/shorts/eGaou1zQUZ8)

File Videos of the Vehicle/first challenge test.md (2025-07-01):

[First challenge](https://youtube.com/shorts/cBEeWWgM5bk)

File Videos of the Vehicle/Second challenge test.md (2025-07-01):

[Second challenge test](https://youtu.be/yUHeHuiJ1uw)

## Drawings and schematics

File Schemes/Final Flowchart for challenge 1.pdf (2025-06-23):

NO

SI

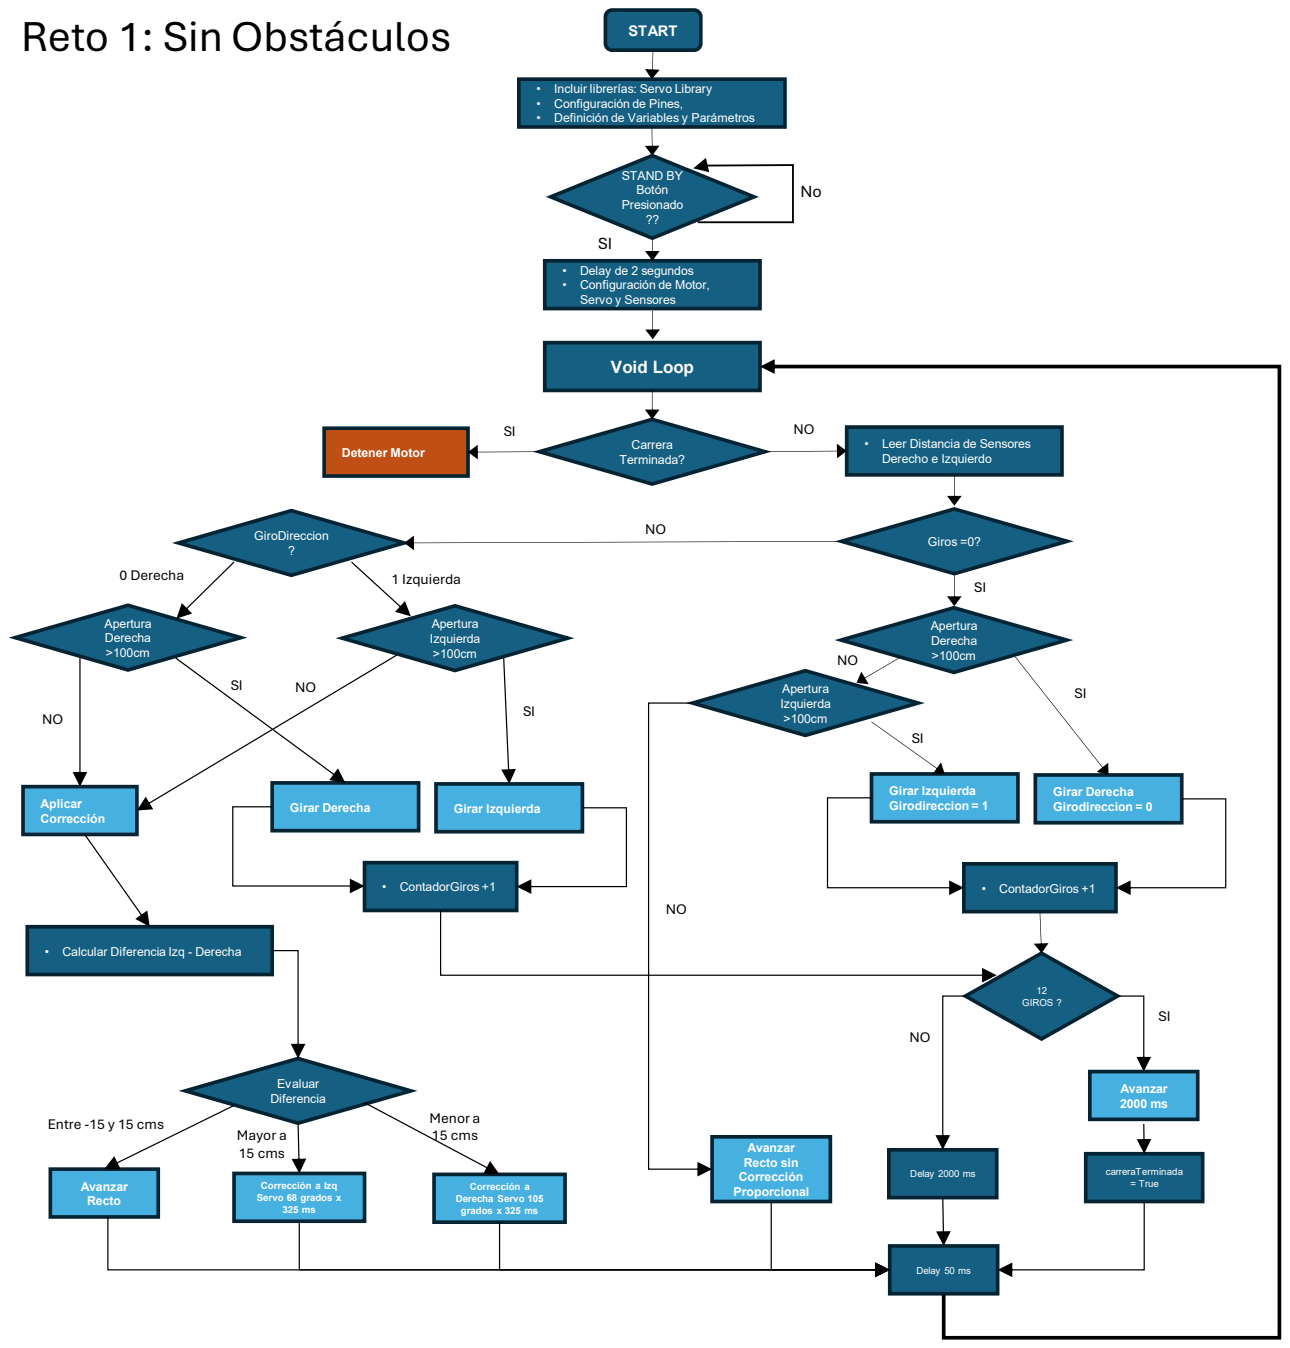
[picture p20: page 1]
START; Carrera Terminada?; Delay 2000 ms; STAND BY Botón Presionado ??; Void Loop; Detener Motor; Giros =0? GiroDireccion ?; • ContadorGiros +1; Apertura Derecha >100cm; Aplicar Corrección; Girar Derecha Girodireccion = 0; Girar Izquierda Girodireccion = 1; Apertura Izquierda >100cm; 12 GIROS ?; Delay 50 ms; Avanzar 2000 ms; carreraTerminada = True; Avanzar Recto sin Corrección Proporcional; 0 Derecha; 1 Izquierda; Girar Derecha; Girar Izquierda; Evaluar Diferencia; Avanzar Recto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

Reto 1: Sin Obstáculos

• Incluir librerías: Servo Library
• Configuración de Pines,
• Definición de Variables y Parámetros

• Delay de 2 segundos
• Configuración de Motor,
Servo y Sensores

• Leer Distancia de Sensores
Derecho e Izquierdo

• Calcular Diferencia Izq - Derecha

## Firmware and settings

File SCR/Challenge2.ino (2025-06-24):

#include <Servo.h>
#include <Pixy2.h>

// Configuración de pines del motor
#define ENB 10
#define IN4 11
#define IN3 12

// Configuración del servo
#define SERVO_PIN 9
#define SERVO_CENTER 88
#define SERVO_LEFT 43
#define SERVO_RIGHT 133

// Configuración de sensores ultrasónicos
#define TRIG_RIGHT 2
#define ECHO_RIGHT 3
#define TRIG_LEFT 4
#define ECHO_LEFT 5

// Parámetros generales
#define MOTOR_SPEED 110              // Velocidad reducida para mejor control
#define MOTOR_SPEED_EVASION 100      // Velocidad durante evasión
#define APERTURA_UMBRAL 60           // 60cm
#define TIEMPO_GIRO 1500             // ms
#define DELAY_POST_GIRO 1200         // ms
#define NUM_LECTURAS 3               // Número de lecturas para confirmar
#define MAX_GIROS 12                 // número máximo de giros antes de detenerse
#define TIEMPO_AVANCE_FINAL 800      // ms - tiempo de avance después del último giro

// Parámetros de navegación visual
#define GANANCIA_CAMARA 0.1          // Qué tan agresivo seguir el obstáculo
#define DISTANCIA_EVASION 25         // cm - cuándo empezar a evadir
#define ANCHO_MIN_OBSTACULO 15       // píxeles - tamaño mínimo para considerar válido
#define CENTRO_CAMARA 158            // Centro horizontal de la Pixy (315/2)

// Parámetros de evasión
#define SERVO_EVASION_IZQ 60         // Ángulo para evadir por izquierda
#define SERVO_EVASION_DER 120        // Ángulo para evadir por derecha
#define TIEMPO_EVASION_FASE1 700     // ms - Alejarse del obstáculo
#define TIEMPO_EVASION_FASE2 700     // ms - Volver al centro

// Parámetros de centrado inicial
#define UMBRAL_CENTRADO_INICIAL 10
#define VELOCIDAD_CENTRADO 130
#define TIEMPO_CENTRADO_FASE1 1200
#define TIEMPO_CENTRADO_FASE2 1100
#define SERVO_CENTRADO_IZQ 43
#define SERVO_CENTRADO_DER 133
#define SERVO_CENTRADO_CONTRA_IZQ 110
#define SERVO_CENTRADO_CONTRA_DER 80

// Configuración de Pixy - Signatures
#define SIG_ROJO 3    // Asignar en Pixy
#define SIG_VERDE 2   // Asignar en Pixy

// Objetos
Servo servoMotor;
Pixy2 pixy;

// Variables globales
float distanciaDerecha = 0;
float distanciaIzquierda = 0;
int contadorGiros = 0;
bool carreraTerminada = false

// Estructura para info del obstáculo
struct Obstaculo {
  bool detectado;
  int x;
  int y;
  int ancho;
  int alto;
  int signature;  // 1=rojo, 2=verde
  float distanciaEstimada;
};

Obstaculo obstaculoActual;

void setup() {
  Serial.begin(115200);
  
  // Configurar pines del motor
  pinMode(ENB, OUTPUT);
  pinMode(IN4, OUTPUT);
  pinMode(IN3, OUTPUT);
  
  // Configurar servo
  servoMotor.attach(SERVO_PIN);
  servoMotor.write(SERVO_CENTER);
  
  // Configurar pines de sensores ultrasónicos
  pinMode(TRIG_RIGHT, OUTPUT);
  pinMode(ECHO_RIGHT, INPUT);
  pinMode(TRIG_LEFT, OUTPUT);
  pinMode(ECHO_LEFT, INPUT);
  
  // Inicializar Pixy
  pixy.init();
  
  Serial.println("Sistema listo!");
  Serial.print("Configurado para ");
  Serial.print(MAX_GIROS);
  Serial.println(" giros máximo");
  delay(2000);
  
  // Ejecutar centrado inicial
  centradoInicial();
}

void loop() {
  // Si ya se completaron los giros máximos, no hacer nada
  if (carreraTerminada) {
    detener(
    return
  }
  
  // Leer sensores ultrasónicos
  distanciaDerecha = leerSensorPromedio(TRIG_RIGHT, ECHO_RIGHT);
  distanciaIzquierda = leerSensorPromedio(TRIG_LEFT, ECHO_LEFT);
  
  // Buscar obstáculos con Pixy
  detectarObstaculo();
  
   Debug
  Serial.print("Giro #");
  Serial.print(contadorGiros);
  Serial.print(" | D: ");
  Serial.print(distanciaDerecha);
  Serial.print(" | I: ");
  Serial.print(distanciaIzquierda);
  if (obstaculoActual.detectado) {
    Serial.print(" | Obs: ");
    Serial.print(obstaculoActual.signature == SIG_ROJO ? "ROJO" : "VERDE");
    Serial.print(" X:");
    Serial.print(obstaculoActual.x);
    Serial.print(" Dist:");
    Serial.print(obstaculoActual.distanciaEstimada);
  }
  Serial.println();
  
  // Lógica de control principal
  if (obstaculoActual.detectado) {
    // Modo navegación visual
    navegarHaciaObstaculo();
  } 
  else if (distanciaDerecha > APERTURA_UMBRAL) {
    // Detectada apertura a la derecha
    Serial.println("Apertura detectada a la DERECHA");
    girarDerecha();
    delay(DELAY_POST_GIRO);
  } 
  else if (distanciaIzquierda > APERTURA_UMBRAL) {
    // Detectada apertura a la izquierda
    Serial.println("Apertura detectada a la IZQUIERDA");
    girarIzquierda();
    delay(DELAY_POST_GIRO);
  } 
  else {
    // Sin obstáculos ni aperturas - avanzar recto
    avanzar();
  }
  
  delay(50); // Pequeña pausa para estabilidad
}

// Función para detectar obstáculos con Pixy
void detectarObstaculo() {
  obstaculoActual.detectado = false;
  
  // Obtener bloques de la Pixy
  pixy.ccc.getBlocks();
  
  if (pixy.ccc.numBlocks) {
    // Buscar el obstáculo más grande/cercano
    int mejorBloque = -1;
    int mayorArea = 0;
    
    for (int i = 0; i < pixy.ccc.numBlocks; i++) {
      // Solo considerar bloques rojos o verdes
      if (pixy.ccc.blocks[i].m_signature == SIG_ROJO || 
          pixy.ccc.blocks[i].m_signature == SIG_VERDE) {
        
        int area = pixy.ccc.blocks[i].m_width * pixy.ccc.blocks[i].m_height;
        
        // Filtrar por tamaño mínimo
        if (area > mayorArea && pixy.ccc.blocks[i].m_width > ANCHO_MIN_OBSTACULO) {
          mejorBloque = i;
          mayorArea = area;
        }
      }
    }
    
    // Si encontramos un bloque válido
    if (mejorBloque >= 0) {
      obstaculoActual.detectado = true;
      obstaculoActual.x = pixy.ccc.blocks[mejorBloque].m_x;
      obstaculoActual.y = pixy.ccc.blocks[mejorBloque].m_y;
      obstaculoActual.ancho = pixy.ccc.blocks[mejorBloque].m_width;
      obstaculoActual.alto = pixy.ccc.blocks[mejorBloque].m_height;
      obstaculoActual.signature = pixy.ccc.blocks[mejorBloque].m_signature;
      
      // Estimar distancia basada en el tamaño del objeto
      // Calibrar estos valores según pruebas reales
      obstaculoActual.distanciaEstimada = 3000.0 / obstaculoActual.alto;
    }
  }
}

// Función para navegar hacia el obstáculo detectado
void navegarHaciaObstaculo() {
  // Verificar si estamos lo suficientemente cerca para evadir
  if (obstaculoActual.distanciaEstimada < DISTANCIA_EVASION) {
    if (obstaculoActual.signature == SIG_VERDE) {
      Serial.println("Evadiendo obstáculo VERDE por la IZQUIERDA");
      evadirPorIzquierda();
    } else {
      Serial.println("Evadiendo obstáculo ROJO por la DERECHA");
      evadirPorDerecha();
    }
  } else {
    // Navegar hacia el obstáculo manteniéndolo centrado
    int error = obstaculoActual.x - CENTRO_CAMARA;
    
    // Calcular ángulo del servo basado en el error
    // El error puede ser de -158 a +158, queremos mapear a un rango de servo útil
    float errorNormalizado = (float)error / CENTRO_CAMARA; // -1 a +1
    int anguloServo = SERVO_CENTER + (errorNormalizado * 20 * GANANCIA_CAMARA);
    
    // Limitar el ángulo
    anguloServo = constrain(anguloServo, 70, 110);
    
    // Aplicar corrección
    servoMotor.write(anguloServo);
    
    // Avanzar
    digitalWrite(IN3, HIGH);
    digitalWrite(IN4, LOW);
    analogWrite(ENB, MOTOR_SPEED);
  }
}

// Función para evadir por la izquierda
void evadirPorIzquierda() {
  // Fase 1: Girar a la izquierda
  servoMotor.write(SERVO_EVASION_IZQ);
  digitalWrite(IN3, HIGH);
  digitalWrite(IN4, LOW);
  analogWrite(ENB, MOTOR_SPEED_EVASION);
  delay(TIEMPO_EVASION_FASE1);
  
  // Fase 2: Enderezar con contra-giro
  servoMotor.write(SERVO_EVASION_DER - 20); // Contra-giro suave
  delay(TIEMPO_EVASION_FASE2);
  
  // Volver al centro
  servoMotor.write(SERVO_CENTER);
  
  // Pequeña pausa para estabilizar
  delay(200);
}

// Función para evadir por la derecha
void evadirPorDerecha() {
  // Fase 1: Girar a la derecha
  servoMotor.write(SERVO_EVASION_DER);
  digitalWrite(IN3, HIGH);
  digitalWrite(IN4, LOW);
  analogWrite(ENB, MOTOR_SPEED_EVASION);
  delay(TIEMPO_EVASION_FASE1);
  
  // Fase 2: Enderezar con contra-giro
  servoMotor.write(SERVO_EVASION_IZQ + 20); // Contra-giro suave
  delay(TIEMPO_EVASION_FASE2);
  
  // Volver al centro
  servoMotor.write(SERVO_CENTER);
  
  // Pequeña pausa para estabilizar
  delay(200);
}

// [Mantener todas las funciones anteriores sin cambios]
// Función para leer sensor ultrasónico individual
float leerSensorUltrasonico(int trigPin, int echoPin) {
  digitalWrite(trigPin, LOW);
  delayMicroseconds(2);
  digitalWrite(trigPin, HIGH);
  delayMicroseconds(10);
  digitalWrite(trigPin, LOW);
  
  long duracion = pulseIn(echoPin, HIGH, 30000);
  float distancia = (duracion * 0.0343) / 2;
  
  if (duracion == 0) {
    return 999;
  }
  
  return distancia;
}

// Función para obtener promedio de múltiples lecturas
float leerSensorPromedio(int trigPin, int echoPin) {
  float suma = 0;
  int lecturasValidas = 0;
  
  for (int i = 0; i < NUM_LECTURAS; i++) {
    float lectura = leerSensorUltrasonico(trigPin, echoPin);
    
    if (lectura < 400) {
      suma += lectura;
      lecturasValidas++;
    }
    
    delay(10);
  }
  
  if (lecturasValidas > 0) {
    return suma / lecturasValidas;
  }
  
  return 999;
}

// Funciones de movimiento básicas
void avanzar() {
  digitalWrite(IN3, HIGH);
  digitalWrite(IN4, LOW);
  analogWrite(ENB, MOTOR_SPEED);
  servoMotor.write(SERVO_CENTER);
}

void detener() {
  digitalWrite(IN3, LOW);
  digitalWrite(IN4, LOW);
  analogWrite(ENB, 0);
}

void girarDerecha() {
  contadorGiros++;
  Serial.print("Giro #");
  Serial.print(contadorGiros);
  Serial.println(" a la DERECHA");
  
  servoMotor.write(SERVO_RIGHT);
  digitalWrite(IN3, HIGH);
  digitalWrite(IN4, LOW);
  analogWrite(ENB, MOTOR_SPEED);
  
  delay(TIEMPO_GIRO);
  servoMotor.write(SERVO_CENTER);
  
  if (contadorGiros >= MAX_GIROS) {
    Serial.println("¡Último giro completado! Avanzando un poco más...");
    avanzar();
    delay(TIEMPO_AVANCE_FINAL);
    detener();
    carreraTerminada = true;
    Serial.println("¡Carrera completada!");
  }
}

void girarIzquierda() {
  contadorGiros++;
  Serial.print("Giro #");
  Serial.print(contadorGiros);
  Serial.println(" a la IZQUIERDA");
  
  servoMotor.write(SERVO_LEFT);
  digitalWrite(IN3, HIGH);
  digitalWrite(IN4, LOW);
  analogWrite(ENB, MOTOR_SPEED);
  
  delay(TIEMPO_GIRO);
  servoMotor.write(SERVO_CENTER);
  
  if (contadorGiros >= MAX_GIROS) {
    Serial.println("¡Último giro completado! Avanzando un poco más...");
    avanzar();
    delay(TIEMPO_AVANCE_FINAL);
    detener();
    carreraTerminada = true;
    Serial.println("¡Carrera completada!");
  }
}

// Función de centrado inicial
void centradoInicial() {
  Serial.println("Iniciando fase de centrado...");
  
  float distInicialDerecha = leerSensorPromedio(TRIG_RIGHT, ECHO_RIGHT);
  float distInicialIzquierda = leerSensorPromedio(TRIG_LEFT, ECHO_LEFT);
  
  Serial.print("Distancia inicial - D: ");
  Serial.print(distInicialDerecha);
  Serial.print(" cm | I: ");
  Serial.print(distInicialIzquierda);
  Serial.println(" cm");
  
  float diferencia = distInicialIzquierda - distInicialDerecha;
  
  if (abs(diferencia) > UMBRAL_CENTRADO_INICIAL) {
    digitalWrite(IN3, HIGH);
    digitalWrite(IN4, LOW);
    analogWrite(ENB, VELOCIDAD_CENTRADO);
    
    if (diferencia > 0) {
      Serial.println("Centrado inicial: Fase 1 - Girando IZQUIERDA");
      servoMotor.write(SERVO_CENTRADO_IZQ);
      delay(TIEMPO_CENTRADO_FASE1);
      
      Serial.println("Centrado inicial: Fase 2 - Enderezando con contra-giro DERECHA");
      servoMotor.write(SERVO_CENTRADO_CONTRA_IZQ);
      delay(TIEMPO_CENTRADO_FASE2);
    } else {
      Serial.println("Centrado inicial: Fase 1 - Girando DERECHA");
      servoMotor.write(SERVO_CENTRADO_DER);
      delay(TIEMPO_CENTRADO_FASE1);
      
      Serial.println("Centrado inicial: Fase 2 - Enderezando con contra-giro IZQUIERDA");
      servoMotor.write(SERVO_CENTRADO_CONTRA_DER);
      delay(TIEMPO_CENTRADO_FASE2);
    }
    
    analogWrite(ENB, 0);
    servoMotor.write(SERVO_CENTER);
    
    Serial.println("Centrado inicial completado");
    delay(500);
  } else {
    Serial.println("Ya está centrado - continuando...");
  }
}

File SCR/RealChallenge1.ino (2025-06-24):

#include <Servo.h>

// Configuración de pines del motor
#define ENB 6
#define IN4 7
#define IN3 8

// Configuración del servo
#define SERVO_PIN 9
#define SERVO_CENTER 88
#define SERVO_LEFT 43
#define SERVO_RIGHT 133

// Configuración de sensores ultrasónicos
#define TRIG_RIGHT 2
#define ECHO_RIGHT 3
#define TRIG_LEFT 4
#define ECHO_LEFT 5

// Parámetros
#define MOTOR_SPEED 130
#define APERTURA_UMBRAL 70      // 70cm
#define TIEMPO_GIRO 1600        // ms - actualizado
#define DELAY_POST_GIRO 1500    // ms - actualizado
#define NUM_LECTURAS 3          // Número de lecturas para confirmar

// Parámetros de corrección proporcional simple
#define UMBRAL_DIFERENCIA 15    // cm - diferencia mínima entre lados para corregir
#define SERVO_CORRECCION_IZQ 75 // grados - corrección suave a izquierda
#define SERVO_CORRECCION_DER 105 // grados - corrección suave a derecha
#define TIEMPO_CORRECCION 200   // ms - duración de la corrección

// Parámetros de centrado inicial
#define UMBRAL_CENTRADO_INICIAL 10   // cm - diferencia mínima para activar centrado
#define VELOCIDAD_CENTRADO 130       // velocidad del motor durante centrado
#define TIEMPO_CENTRADO_FASE1 1200    // ms - duración del giro inicial
#define TIEMPO_CENTRADO_FASE2 1100    // ms - duración del contra-giro
#define SERVO_CENTRADO_IZQ 43        // grados - ángulo para centrado inicial a izquierda
#define SERVO_CENTRADO_DER 133       // grados - ángulo para centrado inicial a derecha
#define SERVO_CENTRADO_CONTRA_IZQ 110 // grados - contra-giro suave después de ir a izquierda
#define SERVO_CENTRADO_CONTRA_DER 80  // grados - contra-giro suave después de ir a derecha
#define MAX_GIROS 12                 // número máximo de giros antes de detenerse
#define TIEMPO_AVANCE_FINAL 800
int contadorGiros = 0 // ms - tiempo de avance después del último giro

// Objeto servo
Servo servoMotor;

// Variables globales
float distanciaDerecha = 0
float distanciaIzquierda = 0

void setup() {
  Serial.begin(115200);
  
  // Configurar pines del motor
  pinMode(ENB, OUTPUT);
  pinMode(IN4, OUTPUT);
  pinMode(IN3, OUTPUT);
  
  // Configurar servo
  servoMotor.attach(SERVO_PIN);
  servoMotor.write(SERVO_CENTER);
  
  // Configurar pines de sensores ultrasónicos
  pinMode(TRIG_RIGHT, OUTPUT);
  pinMode(ECHO_RIGHT, INPUT);
  pinMode(TRIG_LEFT, OUTPUT);
  pinMode(ECHO_LEFT, INPUT);
  
  Serial.println("Sistema listo!");
  delay(2000);
  
  // Ejecutar centrado inicial
  centradoInicial();
}

void loop() {
  // Leer sensores con múltiples lecturas para confiabilidad
  distanciaDerecha = leerSensorPromedio(TRIG_RIGHT, ECHO_RIGHT);
  distanciaIzquierda = leerSensorPromedio(TRIG_LEFT, ECHO_LEFT);
  
  // Debug - comentar en competencia
  Serial.print("D: ");
  Serial.print(distanciaDerecha);
  Serial.print(" cm | I: ");
  Serial.print(distanciaIzquierda);
  Serial.println(" cm");
  
  // Lógica de control principal
  if (distanciaDerecha > APERTURA_UMBRAL) {
    // Detectada apertura a la derecha
    Serial.println("Apertura detectada a la DERECHA");
    girarDerecha();
    delay(DELAY_POST_GIRO); // Delay adicional para evitar detecciones múltiples
  } 
  else if (distanciaIzquierda > APERTURA_UMBRAL) {
    // Detectada apertura a la izquierda
    Serial.println("Apertura detectada a la IZQUIERDA");
    girarIzquierda();
    delay(DELAY_POST_GIRO); // Delay adicional para evitar detecciones múltiples
  } 
  else {
    // No hay apertura - aplicar corrección proporcional simple
    aplicarCorreccionProporcional();
  }
  
  delay(50); // Pequeña pausa para estabilidad
}

Función de centrado inicial
void centradoInicial() {
  Serial.println("Iniciando fase de centrado...");
  
  // Leer sensores iniciales
  float distInicialDerecha = leerSensorPromedio(TRIG_RIGHT, ECHO_RIGHT);
  float distInicialIzquierda = leerSensorPromedio(TRIG_LEFT, ECHO_LEFT);
  
  // Mostrar lecturas iniciales
  Serial.print("Distancia inicial - D: ");
  Serial.print(distInicialDerecha);
  Serial.print(" cm | I: ");
  Serial.print(distInicialIzquierda);
  Serial.println(" cm");
  
  // Calcular diferencia
  float diferencia = distInicialIzquierda - distInicialDerecha;
  
  // Si la diferencia es significativa, aplicar centrado
  if (abs(diferencia) > UMBRAL_CENTRADO_INICIAL) {
    
    // Iniciar movimiento
    digitalWrite(IN3, HIGH);
    digitalWrite(IN4, LOW);
    analogWrite(ENB, VELOCIDAD_CENTRADO);
    
    if (diferencia > 0) {
      // Muy cerca de la pared derecha - maniobra hacia la izquierda
      Serial.println("Centrado inicial: Fase 1 - Girando IZQUIERDA");
      
       FASE 1: Giro pronunciado hacia el centro
      servoMotor.write(SERVO_CENTRADO_IZQ)
      delay(TIEMPO_CENTRADO_FASE1)
      
      // FASE 2: Contra-giro para enderezar
      Serial.println("Centrado inicial: Fase 2 - Enderezando con contra-giro DERECHA");
      servoMotor.write(SERVO_CENTRADO_CONTRA_IZQ);
      delay(TIEMPO_CENTRADO_FASE2)
      
    } else {
      // Muy cerca de la pared izquierda - maniobra hacia la derecha
      Serial.println("Centrado inicial: Fase 1 - Girando DERECHA");
      
      // FASE 1: Giro pronunciado hacia el centro
      servoMotor.write(SERVO_CENTRADO_DER);
      delay(TIEMPO_CENTRADO_FASE1);
      
      // FASE 2: Contra-giro para enderezar
      Serial.println("Centrado inicial: Fase 2 - Enderezando con contra-giro IZQUIERDA");
      servoMotor.write(SERVO_CENTRADO_CONTRA_DER);
      delay(TIEMPO_CENTRADO_FASE2);
    }
    
    // Detener y enderezar
    analogWrite(ENB, 9);
    servoMotor.write(SERVO_CENTER);
    
    Serial.println("Centrado inicial completado");
    delay(500); // Pequeña pausa antes de continuar
    
  } else {
    Serial.println("Ya está centrado - continuando...");
  }
}

// Función para leer sensor ultrasónico individual
float leerSensorUltrasonico(int trigPin, int echoPin) {
  // Enviar pulso de trigger
  digitalWrite(trigPin, LOW);
  delayMicroseconds(2);
  digitalWrite(trigPin, HIGH);
  delayMicroseconds(10);
  digitalWrite(trigPin, LOW);
  
  // Leer el tiempo del echo
  long duracion = pulseIn(echoPin, HIGH, 30000); // Timeout de 30ms
  
  // Calcular distancia en cm
  // Velocidad del sonido = 343 m/s = 0.0343 cm/us
  // Distancia = (tiempo * velocidad) / 2
  float distancia = (duracion * 0.0343) / 2;
  
  // Si no hay lectura válida, retornar valor alto
  if (duracion == 0) {
    return 999;
  }
  
  return distancia;
}
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

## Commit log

2025-06-15 Create Link for the servomotor video
2025-06-23 Add files via upload
    In this commit, we add a PDF of which motors we use, how we put it, and why we use them
2025-06-23 Update README.md adding the ackerman steering mechanism explaination
2025-06-23 Upload of the final flowchart for challenge 1
2025-06-23 Upload of the description of the Flowchart 1 final
2025-06-24 PDF of detailed power consumption
2025-06-24 putting old vehicles photo in prototypes
2025-07-01 Update Servo test.md
2025-07-11 Create Two finger video
2025-07-11 Update Two finger video
2025-07-11 Rename Two finger video to Two finger video.md
2025-08-16 Rename 009 Ajuste Chasis.jpg to 009 parts of the chasis that were cut off.jpg
2025-08-16 Rename 019 Enganajes3.jpg to 019 gear3.jpg
2025-08-16 Rename 018 Enganajes3.jpg to 018 gears2.jpg
2025-08-16 Rename 017 Enganajes3.jpg to 017 gear.jpg
2025-09-20 Update README.md
    addition of the new sensor
